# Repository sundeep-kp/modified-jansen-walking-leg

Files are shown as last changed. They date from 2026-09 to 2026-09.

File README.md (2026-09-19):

Full document here-- https://docs.google.com/document/d/1wQWvOZNvA1PLT6YzGUdqtGpzAtf10ug7fWzOEEy77QI/

preview (does not include assets for now, refer above document as recommended):

# Modified Jansen Walking Mechanism Report

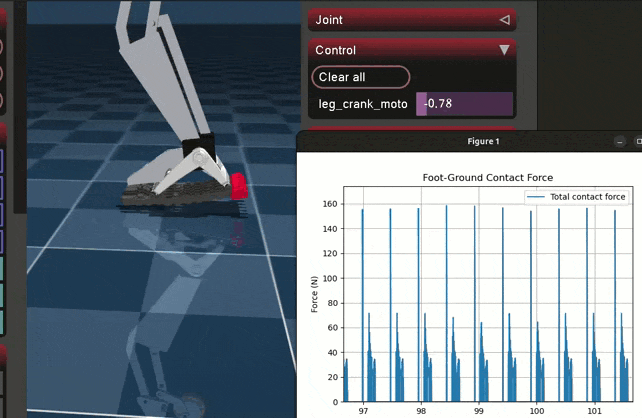
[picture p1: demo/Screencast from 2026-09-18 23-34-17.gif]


## Abstract
Theo Jansen's linkage is a well-known single-degree-of-freedom, eight-bar planar mechanism that converts rotary input into a leg-like walking trajectory. The objective of this project was to reduce the visual and part-count complexity of the standard Jansen leg — consolidating links where they do not affect the underlying kinematics — while keeping the mechanism at one degree of freedom and retaining a Jansen-like foot trajectory that closely matched human gait.

The design was carried out in SolidWorks, using its Motion Study add-in to verify the trajectory and animate the assembled mechanism, and later reconstructed in MuJoCo to evaluate contact dynamics and inform a physical build.

This reduced mechanism is a compact re-interpretation of the standard Jansen leg, in which several links were merged or removed for compactness without altering the underlying kinematic behaviour.

## 1. Introduction

Theo Jansen's linkage is a well-known single-degree-of-freedom, eight-bar planar mechanism that converts rotary input into a leg-like walking trajectory. The objective of this project was to reduce the visual and part-count complexity of the standard Jansen leg — consolidating links where they do not affect the underlying kinematics — while keeping the mechanism at one degree of freedom and retaining a Jansen-like foot trajectory that closely matched human gait. The design was carried out in SolidWorks, using its Motion Study add-in to verify the trajectory and animate the assembled mechanism, and later reconstructed in MuJoCo to evaluate contact dynamics and inform a physical build.

## 2. Mechanism Overview

The design is a reduced re-interpretation of the standard Jansen leg (Fig. 1), in which several links were merged or removed for compactness without altering the underlying kinematic behaviour.

Figure 1. The reduced mechanism (left) alongside the reference eight-bar Jansen linkage it is derived from (right).

### 2.1 Topology Reduction

The bottom horizontal link was removed and the two lower-left links were straightened into a single rigid link.

The upper-right horizontal link and the middle-right link were removed and replaced with one rigid bent link (shown in yellow in Fig. 3), which is a compaction choice rather than a kinematic change.

Ignoring the foot and the outermost link that drives it, the crank disk becomes the effective ground-mounted driver.

Figure 2. Before (left) and after (right) consolidating the lower-leg links into a single rigid member.

This reduction is visual rather than kinematic: the point where the lower right link meets the ternary (triangular) link is still pinned to the ground in the underlying sketch, even though this is not obvious from the solid geometry alone. The mechanism therefore reduces, functionally, to the same four-bar linkage present in the upper-right portion of the standard Jansen leg.

### 2.2 The Driving Four-Bar Subsystem

Colour-coding the assembly makes the reduction explicit (Fig. 3): the crank disk (black) rotates about the fixed ground pivot, driving the coupler link (blue), which in turn drives the ternary link (red). The ternary link is itself pinned to ground at a second, fixed point — completing the crank-rocker four-bar. The bent link (yellow) is an output link riding on the ternary link, carrying motion down to the lower leg (grey).

Figure 3. Colour-coded four-bar subsystem — crank (black), coupler (blue), ternary/rocker link (red), and the output bent link (yellow).

## 3. Methodology

The mechanism was built up incrementally in SolidWorks, verifying at each stage that the added constraints produced the intended single-degree-of-freedom behaviour before proceeding.

### 3.1 Ground Link and Ternary Link Placement

A disk was used as the ground link. One corner of the ternary link was pinned to this ground link at a separation of 15.8 mm (Fig. 4). The ternary link was chosen as the member fixed to ground because it plays the same structural role as the corresponding rocker link in the upper four-bar of the standard Jansen leg (Section 2.2); the 15.8 mm separation itself was arrived at empirically, by sweeping the dimension and observing its effect on the foot trajectory — this trade-off is examined in Section 4.2.

Figure 4. Ternary link sketch showing the fixed-pivot separation and hole geometry.

### 3.2 Crank–Coupler Assembly

A second disk was added as the crank, driven by a protruding input shaft, and connected to the ternary link through a coupler link (Fig. 5). This sub-assembly is a crank-rocker four-bar mechanism [1], with the crank providing continuous rotary input and the ternary link rocking in response.

Figure 5. Crank–coupler–ternary link four-bar sub-assembly.

### 3.3 Constraining the Lower Leg

With only the four-bar and the lower leg links connected, the assembly was under-constrained: each crank angle admitted multiple valid positions for the lower leg. An additional bent link, dimensioned as shown in Fig. 6 (9.86 mm and 12.83 mm segments at 139.31°), was introduced to remove this ambiguity and fully constrain the leg to a single configuration per input angle. The remaining sketch dimensions for this stage of the assembly are given in Fig. 7.

Figure 6. Bent-link geometry added to remove the residual assembly ambiguity.

Figure 7. Fully dimensioned four-bar and lower-leg sketch after the additional constraint was applied.

### 3.4 Leg Assembly, Mirroring, and Coupling

The completed leg was assembled and mirrored using SolidWorks' “create opposite hand components” option, and the mirrored files were saved and reassembled independently. Both legs were then joined by a connecting link (highlighted in blue in Fig. 8), which mechanically couples them to a single common input — keeping the overall mechanism at one degree of freedom while the two legs remain permanently offset by a phase difference. This offset was set experimentally (matching the legs at their extremum positions) to give a more natural walking gait.

Figure 8. Both legs coupled through a common connecting link (blue), sharing a single driven input.

### 3.5 Padding and Animation

Foot padding was added to each leg, and the assembly was driven with a simple rotary motor input in a SolidWorks Motion Study to animate the complete walking cycle (see Fig. 10, Section 5).

## 4. Kinematic Analysis

The modified mechanism retains several dimensional characteristics of the conventional Jansen linkage. Table 1 compares the measured link dimensions of this design against the closest corresponding dimensions of the standard Jansen linkage.

Table 1. Measured link dimensions versus standard Jansen proportions.

| Mechanism feature | Measured value (mm) | Closest Jansen value (mm) | Difference |
| --- | ---: | ---: | ---: |
| Upper crank / ternary-link connection | 23.24 | 15.0 | +54.9% |
| Upper fixed-pivot separation | 24.19 | 15.0 | +61.3% |
| Upper (major) coupler link | 44.02 | 41.5 | +6.1% |
| Major lower-leg link | 37.92 | 38.0 | −0.2% |
| Short lower connector | 14.58 | 15.0 | −2.8% |
| Small connector | 7.39 | 7.8 | −5.3% |
| Bent-link segment (short arm) | 9.86 | 7.8 | +26.4% |
| Bent-link segment (long arm) | 12.83 | 15.0 | −14.5% |
| Long lower-leg dimension | 61.08 | 61.9 | −1.3% |
| Upper positional dimension | 13.00 | 15.0 | −13.3% |
| Component offset | 43.17 | 41.5 | +4.0% |

The lower-leg dimensions (37.92 mm, 14.58 mm, 61.08 mm) track the standard Jansen values (38 mm, 15 mm, 61.9 mm) closely, to within about 3%. The upper four-bar dimensions, by contrast, deviate substantially — in places by more than 50% — reflecting the deliberate re-proportioning of this stage to accommodate the reduced topology and a more compact envelope.

### 4.1 Foot Trajectory

The traced path of a point at the centre of the foot's bottom face (Fig. 9) depends on both the input crank angle and the link dimensions and separations described above. To evaluate how human-like the resulting gait is, the traced path is compared directly against a reference human walking trajectory [7] and against the standard Jansen trajectory [6].

Figure 9a. Traced trajectory of the foot contact point of this mechanism, over one input revolution. (mirrored during simulation)

Figure 9b. Reference human walker gait trajectory [7].

Figure 9c. Reference standard Jansen mechanism gait trajectory [6].

### 4.2 Effect of the 15.8 mm Pivot Separation

The separation between the ground pivot and the ternary link (Section 3.1) was found to directly shape the trajectory:

- At 15.8 mm, the trajectory is somewhat front-heavy.
- Increasing the separation moves the path closer to the stretched-D shape of the standard Jansen trajectory.
- Increasing it further makes the trajectory back-heavy.
- Decreasing it too far causes the four-bar to lose continuous rotary motion — consistent with the mechanism moving out of a Grashof-satisfying link proportion, though this was not formally verified against Grashof's condition in this iteration.

The final value of 15.8 mm was retained because it produces a trajectory whose apex sits slightly forward of centre, relative to the standard Jansen path. This was a deliberate design choice, motivated by three considerations: it mimics human stride, where the apex of foot motion typically sits ahead of the body rather than at its midpoint; it reduces the stride length, improving stability and reliability; and it produces a smoother displacement curve, with a more gradual transition from the rising to the falling phase of the stride.

### 4.3 Results

The completed assembly was driven with a simple rotary motor input and animated in SolidWorks Motion Study (Fig. 10), confirming that the coupled two-leg mechanism produces continuous, single-DOF walking motion with the intended phase offset between legs.

Figure 10. Animated mechanism during a Motion Study walking-cycle simulation.

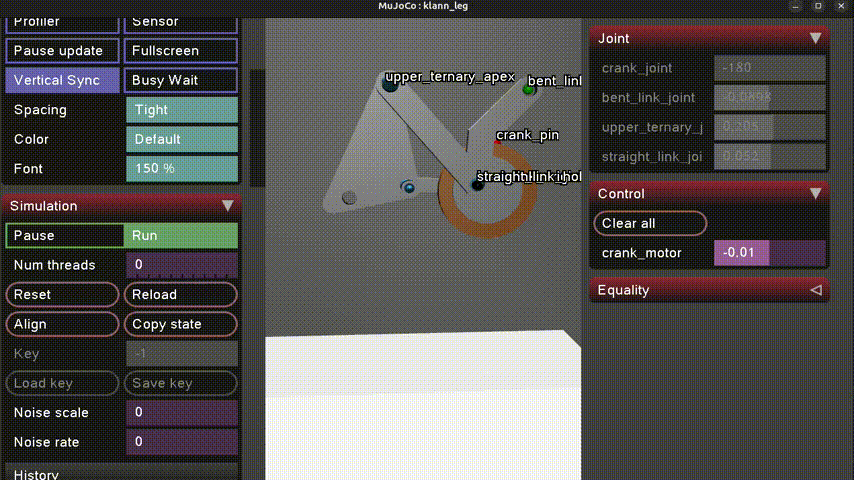
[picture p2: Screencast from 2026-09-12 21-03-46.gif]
Animated mechanism during Motion Study


Simulation video: https://youtu.be/PFEDmKlTlRk?si=vWkerZGaBaEz1gjp

## 5. Simulation

To evaluate contact dynamics that are not readily accessible in the SolidWorks Motion Study — in particular, foot–ground contact forces through a compliant shoe — the mechanism was reconstructed as a physics simulation in MuJoCo.

### 5.1 Link Naming and Digitised Geometry

Before reconstructing the mechanism outside SolidWorks, every link and joint was given a consistent name, and every relevant dimension was measured directly from the CAD model. This naming convention (Fig. 11) was used throughout the MuJoCo model and its XML description.

Figure 11. Link and joint naming convention used for the MuJoCo reconstruction.

The corresponding measured dimensions are summarised in Table 2, with the upper ternary link's sketch dimensions shown as a representative example in Fig. 12. The foot outline was digitised as a series of edge lengths in the same way — Fig. 13 shows one representative measurement — in order to reproduce the exact collision geometry of the physical foot in simulation.

Table 2. Named-link dimensions used for the MuJoCo reconstruction.

| Named link | Feature | Value |
| --- | --- | --- |
| Upper ternary link | joint_3–joint_4 | 21.00 mm |
| Upper ternary link | joint_4–joint_5 | 12.00 mm |
| Upper ternary link | joint_3–joint_5 | 24.19 mm |
| Upper ternary link | Enclosed area / perimeter | 146.87 mm² / 53.41 mm |
| Straight link (upper ternary → lower ternary) | Length | 15.80 mm |
| Bent link (upper ternary → lower ternary) | Segments / angle | see Fig. 6–7 |
| Lower ternary link | Long edge | 37.72 mm |
| Lower ternary link | Offset / short edge | 2.50 mm |
| Lower ternary link | Included angle | 153.74° |
| Lower ternary link | Third edge | 11.33 mm |
| Foot link | Main structural dims | 13.00 mm, 61.08 mm (R1.00 fillet) |
| Foot link | Digitised outline segments | 14.69, 22.66, 25.48, 2.3, 20.7, 15.33, 7.28, 3.12 mm |

Figure 12. Upper ternary link sketch dimensions (joint_3–joint_4–joint_5), representative of the dimensioning pass summarised in Table 2.

Figure 13. Representative foot-outline edge measurement; the full outline was digitised edge-by-edge in the same way for the simulation collision mesh.

### 5.2 MJCF Reconstruction and Closing Kinematic Loops

The mechanism was recreated by importing meshes extracted from the SolidWorks assembly, one link at a time, into the MuJoCo viewer using the native MJCF format. A closed-loop four-bar linkage example [8] was used as a reference for handling kinematic loops in MuJoCo, since MJCF natively describes open kinematic trees.

A joint was defined for each parent–child link pair. To close the two kinematic loops (the driving four-bar, and the lower-leg loop), equality constraints were used to connect pairs of defined sites — specifically, coincident points on the “straight link” and “base link” bodies that should stay joined during motion.

Figure 14. Initial four-bar sub-mechanism reconstructed in the MuJoCo viewer.

Initially, the constrained bodies did not feel rigidly connected — instead behaving as though attracted like magnets rather than pinned together. Investigating further, this was traced to MuJoCo's equality constraints being soft constraints by default: the solver finds constraint forces parameterised by impedance, stiffness (k), and damping (b), and the solref parameter controls the reference acceleration — i.e. how quickly the constraint tries to correct a violation. Tuning these parameters resolved the apparent “magnetic” behaviour and produced a properly closed kinematic loop.

Figure 15. Equality-constrained sites (labelled) closing the four-bar kinematic loop.

Figure 16. Full single-leg mechanism (“klann_leg”) reconstructed and closed in MuJoCo.

Figure 17. Iterating on the MJCF description (modified_jansen_leg.xml) alongside the live MuJoCo viewer.

### 5.3 Deformable Shoe and Contact Physics

To estimate realistic foot–ground contact behaviour, a deformable shoe body was added at the foot link, modelled as a soft body rather than a rigid one.

Attempt 1: with a low number of mesh nodes, the deformable body was unstable and produced unreliable contact behaviour.

Increasing the node count produced stable results; the overall system was then scaled to match adult foot dimensions.

With most of the system stable, the deformable shoe began passing through the floor plane under load.

Figure 18. Early instability: the deformable shoe penetrating through the floor plane.

This penetration was resolved by tuning the shoe's approximate material properties and the solver's contact-correction behaviour, referring to MuJoCo's contact-physics documentation [9] for the relevant parameters:

```text
young = "8e4"          (Young's modulus, lowered for visualisation purposes)
damping = "0.001"
poisson = "0.2"
solref = "0.003 1"    (controls how quickly the constraint corrects penetration)
solimp = ".95 .99 .0001"
```

The width of the floor plane was also increased to prevent contact “bleeding” under a high node count, following a known issue reported against MuJoCo on GitHub.

Figure 19. Deformable shoe resting stably on the floor plane after parameter tuning.

Figure 20. Shoe visually attached to the foot link of the reconstructed mechanism.

### 5.4 Simulated Contact Loading

With the geometry and contact model in place, the link dimensions and masses were finalised, assuming the links to be aluminium, the shoe to be the mass of a standard adult male shoe (~300 g), and the drive motor's weight to initially be that of a standard 1.7 N motor. Figure 21 shows the theoretical contact force at the FSR location under the base of the big toe, over one walking cycle, at an input torque of 0.08 N·m.

Figure 21. Theoretical contact force at the big-toe FSR location over one walking cycle, at 0.08 N·m input torque.

## 6. Proposed Hardware

Based on the simulated loading in Section 6.4, the following hardware was proposed for a physical build of the mechanism.

### 6.1 Proposed Components

- 12 V OG555 geared motor with encoder — crank drive.
- ESP32 — main microcontroller.
- BTS7960 (or equivalent high-power H-bridge capable of handling the 12 V motor).
- AS5600 — for measuring foot orientation at a given time.
- MPU6050 — standard IMU used for acceleration measurement in this class of project.
- Adafruit Alpha MF01A-N-221-A05 force sensor (rated 1–100 N contact force, <1 ms response, with a mature ESP32-compatible library), used at three standard foot contact points: heel, big toe, and little toe. Alternative: load cell + HX711.
- Mean Well LRS-75-12 power supply — 12 V, 6 A adjustable, providing headroom for future add-ons.

### 6.2 Control Architecture

The proposed control loop drives the crank through a speed/position controller on the ESP32, and closes the loop on foot contact and orientation sensing:

```text
+---------------------------+
|          ESP32 MCU         |
|                             |
Desired crank ---->|  Speed / Position Controller|
speed          |             |               |
+-------------+---------------+
| PWM / DIR
v
+--------------+
| BTS7960 /    |
| H-Bridge     |
+------+-------+
|
+------v-------+
| 12 V OG555   |
| Geared Motor |
+------+-------+
|
CRANK
|
+------v-------+
|   LINKAGE    |
+------+-------+
|
FOOT
|
+-------------------+-------------------+
|                   |                   |
Heel FSR           Big-toe FSR        Little-toe FSR
|                   |                   |
+-------------------+-------------------+
|
v
+--------------+
|    ESP32     |
|  Contact     |
|  detection   |
+--------------+
Motor encoder ------------------------------> ESP32
AS5600 --------------------------------------> ESP32
MPU6050 -------------------------------------> ESP32
```

Figure 22. Proposed control architecture: crank speed/position control, closed with foot-contact and orientation sensing.

## 7. Conclusion and Future Work

This project reduced the standard eight-bar Jansen leg to a more compact topology built around a single crank-rocker four-bar, while keeping the mechanism at one degree of freedom and tuning its foot trajectory to sit closer to a human gait than the standard Jansen path. The lower-leg dimensions retained close agreement with the classical Jansen proportions (Section 4), while the upper four-bar was deliberately re-proportioned for the reduced topology and a more compact envelope. Mirroring and coupling the leg into a two-leg, single-input assembly, and animating it in SolidWorks Motion Study, confirmed that the design behaves as intended (Section 5).

The mechanism was then carried substantially further than a CAD exercise: it was reconstructed link-by-link as a physics simulation in MuJoCo, with closed kinematic loops, a deformable contact shoe, and a theoretical contact-force estimate at the big toe (Section 6). That simulated loading, in turn, informed a concrete proposed hardware architecture — drive motor, motor driver, microcontroller, orientation and contact sensing, and power supply — with a defined control loop from desired crank speed through to foot-contact detection (Section 7). Taken together, the project now spans the full path from a first-principles kinematic reduction to a build-ready hardware and control specification.

The most valuable next steps follow directly from where this iteration stopped short:

- Formally verifying the degrees of freedom of the coupled two-leg assembly and the Grashof condition of the driving four-bar using Grübler's equation, rather than relying on the empirical observation in Section 4.2.
- Quantifying the trajectory sweep described in Section 4.2 with a table or plot of pivot separation versus trajectory apex position, instead of the qualitative front-heavy/back-heavy description used here.
- Validating the MuJoCo contact-force estimate (Section 6.4) against the physical prototype once built, and tuning the deformable shoe parameters accordingly.
- Physically fabricating the mechanism and the proposed hardware in Section 7, and closing the control loop on real sensor data rather than simulated values.

## References

- [1] Four bar crank-rocker mechanism demonstration. https://www.youtube.com/watch?v=hrvIBtrDNV0
- [2] Theo Jansen mechanism walking demonstration. https://www.youtube.com/watch?v=clGEbGLUyoQ
- [3] Theo Jansen mechanism build/analysis video. https://www.youtube.com/watch?v=vAEZ4BYAmGE&t=120s
- [4] The Jansen leg: a 1-degree-of-freedom planar linkage of eight links, seven revolute joints. ResearchGate figure. https://www.researchgate.net/figure/The-Jansen-leg-a-1-degree-of-freedom-planar-linkage-of-eight-links-seven-revolute_fig2_277606519
- [5] Educational model of the Theo Jansen mechanism. https://www.printables.com/model/1503557-educational-model-of-theo-jansen-mechanism
- [6] Theo Jansen mechanism reference video. https://www.youtube.com/watch?v=FFuDU1Uiu9k
- [7] Reference human walker gait — acceleration carries the local inversion effect in biological motion perception. https://www.researchgate.net/figure/The-full-gait-trajectory-with-the-10-starting-positions-A-and-the-individual-150-ms_fig1_24187266
- [8] Closed-loop simulation example (four-bar linkage) in MuJoCo, using equality constraints. https://github.com/google-deepmind/mujoco/issues/172
- [9] Reference for deformable-body contact physics parameters used in Section 6.3. https://arxiv.org/html/2411.14701v1

### Project Files

- [modified_jansen_leg.xml](modified_jansen_leg.xml)
- [modified_jansen_leg_adult_male_shoe.xml](modified_jansen_leg_adult_male_shoe.xml)
- [modified_jansen_leg_scaled_4x.xml](modified_jansen_leg_scaled_4x.xml)
- [modified_jansen_leg_visual_shoe.xml](modified_jansen_leg_visual_shoe.xml)
- [reference.xml](reference.xml)
- [template_mujoco.py](template_mujoco.py)

## Appendix: Repository Snapshot

This folder contains the MuJoCo model files, the SolidWorks-derived mesh assets, and the report media used for the walking mechanism design and validation work.

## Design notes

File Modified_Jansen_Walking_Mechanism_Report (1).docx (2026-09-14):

Analysis and Implementation of a Modified Jansen-Based Walking Mechanism

Design log and kinematic analysis of a reduced-topology, single-DOF leg mechanism

Simulation demo: https://youtu.be/PFEDmKlTlRk?si=vWkerZGaBaEz1gjp

# Abstract

This report documents the design and kinematic analysis of a reduced Jansen-type walking mechanism. The mechanism's core motion-generation subsystem is a crank-rocker four-bar linkage, to which additional links are coupled to shape the foot trajectory. Starting from the standard eight-bar Jansen leg, several links were consolidated or re-routed to simplify the topology while preserving single-degree-of-freedom motion and mimicking a more human-like gait trajectory. The resulting mechanism was implemented in SolidWorks, mirrored to produce a second leg, and coupled to a common input so that both legs move from a single driven crank. Measured link dimensions are compared against the standard Jansen proportions, the effect of one key dimension on the shape of the foot trajectory is analysed, and the mechanism is reconstructed as a physics simulation in MuJoCo — including a deformable shoe and contact-force estimation — alongside a proposed hardware architecture for physical realisation.

# Table of Contents

1. Introduction ................................................................................................................................................ 1

2. Mechanism Overview .............................................................................................................................. 1

2.1 Topology Reduction ....................................................................................................................... 1

2.2 The Driving Four-Bar Subsystem ................................................................................................. 1

3. Methodology ............................................................................................................................................ 1

3.1 Ground Link and Ternary Link Placement ................................................................................ 1

3.2 Crank–Coupler Assembly ................................................................................................................ 1

3.3 Constraining the Lower Leg ........................................................................................................... 1

3.4 Leg Assembly, Mirroring, and Coupling ................................................................................... 1

3.5 Padding and Animation .................................................................................................................. 1

4. Kinematic Analysis ................................................................................................................................... 1

4.1 Foot Trajectory ................................................................................................................................. 2

4.2 Effect of the 15.8 mm Pivot Separation ........................................................................................ 2

4.3 Results ................................................................................................................................................ 2

5. Simulation ................................................................................................................................................. 2

5.1 Link Naming and Digitised Geometry ........................................................................................ 2

5.2 MJCF Reconstruction and Closing Kinematic Loops ............................................................. 3

5.3 Deformable Shoe and Contact Physics ....................................................................................... 3

5.4 Simulated Contact Loading ........................................................................................................... 4

6. Proposed Hardware ................................................................................................................................ 4

6.1 Proposed Components .................................................................................................................... 4

6.2 Control Architecture ...................................................................................................................... 4

7. Conclusion and Future Work ................................................................................................................ 5

References ..................................................................................................................................................... 5

# 1. Introduction

Theo Jansen's linkage is a well-known single-degree-of-freedom, eight-bar planar mechanism that converts rotary input into a leg-like walking trajectory. The objective of this project was to reduce the visual and part-count complexity of the standard Jansen leg — consolidating links where they do not affect the underlying kinematics — while keeping the mechanism at one degree of freedom and retaining a Jansen-like foot trajectory that closely matched human gait. The design was carried out in SolidWorks, using its Motion Study add-in to verify the trajectory and animate the assembled mechanism, and later reconstructed in MuJoCo to evaluate contact dynamics and inform a physical build.

# 2. Mechanism Overview

The design is a reduced re-interpretation of the standard Jansen leg (Fig. 1), in which several links were merged or removed for compactness without altering the underlying kinematic behaviour.

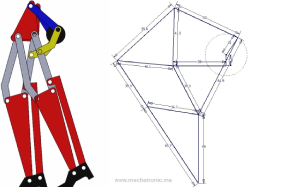
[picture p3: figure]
Comparison of reduced mechanism to standard Jansen linkage

Figure 1. The reduced mechanism (left) alongside the reference eight-bar Jansen linkage it is derived from (right).

## 2.1 Topology Reduction

- The bottom horizontal link was removed and the two lower-left links were straightened into a single rigid link.
- The upper-right horizontal link and the middle-right link were removed and replaced with one rigid bent link (shown in yellow in Fig. 3), which is a compaction choice rather than a kinematic change.
- Ignoring the foot and the outermost link that drives it, the crank disk becomes the effective ground-mounted driver.

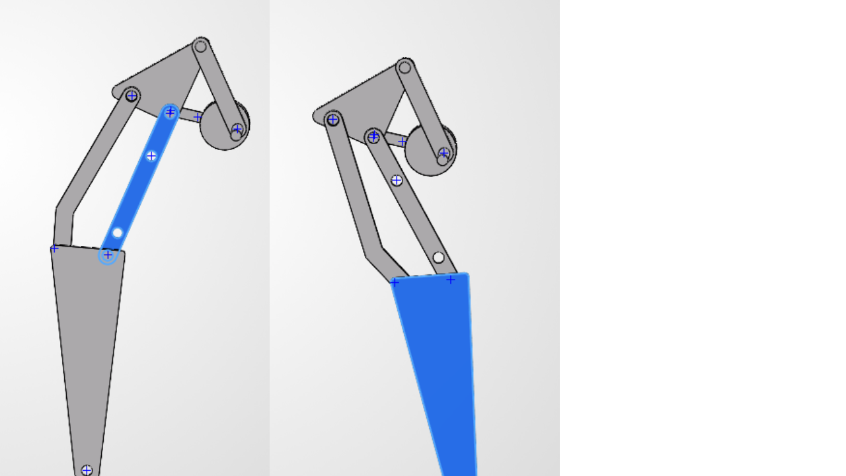
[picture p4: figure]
Before and after link consolidation

Figure 2. Before (left) and after (right) consolidating the lower-leg links into a single rigid member.

This reduction is visual rather than kinematic: the point where the lower right link meets the ternary (triangular) link is still pinned to the ground in the underlying sketch, even though this is not obvious from the solid geometry alone. The mechanism therefore reduces, functionally, to the same four-bar linkage present in the upper-right portion of the standard Jansen leg.

## 2.2 The Driving Four-Bar Subsystem

Colour-coding the assembly makes the reduction explicit (Fig. 3): the crank disk (black) rotates about the fixed ground pivot, driving the coupler link (blue), which in turn drives the ternary link (red). The ternary link is itself pinned to ground at a second, fixed point — completing the crank-rocker four-bar. The bent link (yellow) is an output link riding on the ternary link, carrying motion down to the lower leg (grey).

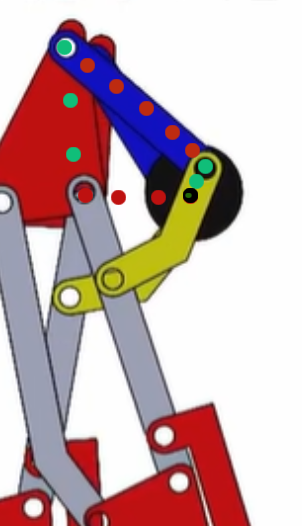
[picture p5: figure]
Color coded four bar subsystem

Figure 3. Colour-coded four-bar subsystem — crank (black), coupler (blue), ternary/rocker link (red), and the output bent link (yellow).

# 3. Methodology

The mechanism was built up incrementally in SolidWorks, verifying at each stage that the added constraints produced the intended single-degree-of-freedom behaviour before proceeding.

## 3.1 Ground Link and Ternary Link Placement

A disk was used as the ground link. One corner of the ternary link was pinned to this ground link at a separation of 15.8 mm (Fig. 4). The ternary link was chosen as the member fixed to ground because it plays the same structural role as the corresponding rocker link in the upper four-bar of the standard Jansen leg (Section 2.2); the 15.8 mm separation itself was arrived at empirically, by sweeping the dimension and observing its effect on the foot trajectory — this trade-off is examined in Section 4.2.

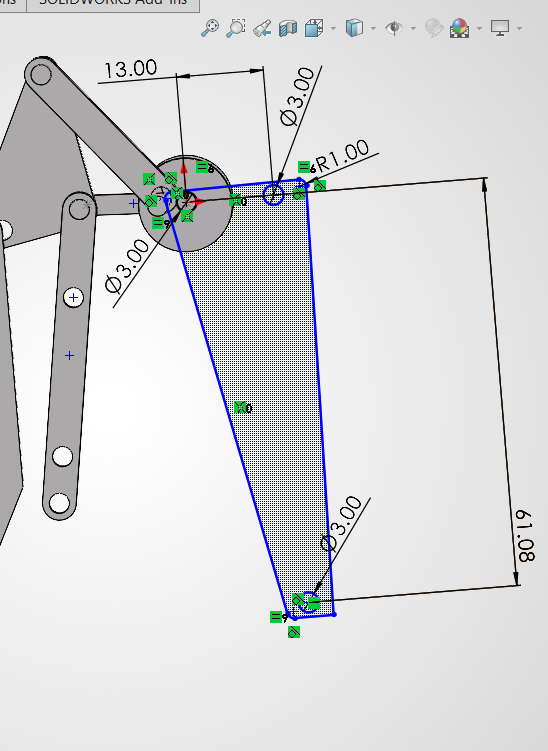
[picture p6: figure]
Ternary link dimension sketch

Figure 4. Ternary link sketch showing the fixed-pivot separation and hole geometry.

## 3.2 Crank–Coupler Assembly

A second disk was added as the crank, driven by a protruding input shaft, and connected to the ternary link through a coupler link (Fig. 5). This sub-assembly is a crank-rocker four-bar mechanism [1], with the crank providing continuous rotary input and the ternary link rocking in response.

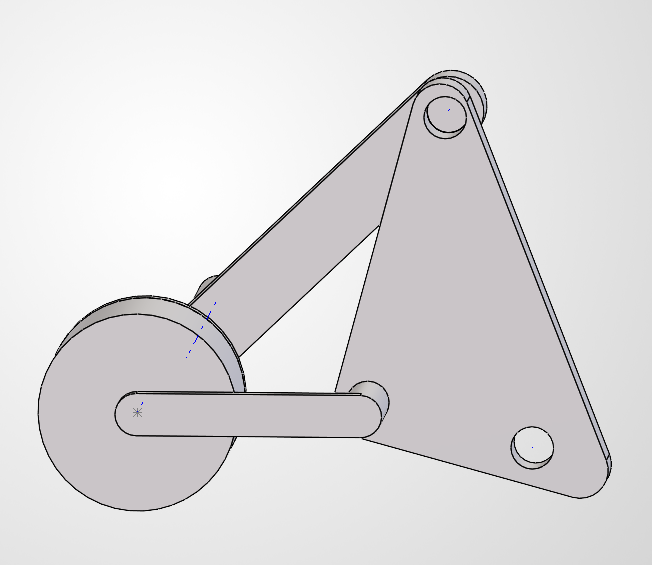
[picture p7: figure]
Crank coupler ternary four bar assembly

Figure 5. Crank–coupler–ternary link four-bar sub-assembly.

## 3.3 Constraining the Lower Leg

With only the four-bar and the lower leg links connected, the assembly was under-constrained: each crank angle admitted multiple valid positions for the lower leg. An additional bent link, dimensioned as shown in Fig. 6 (9.86 mm and 12.83 mm segments at 139.31°), was introduced to remove this ambiguity and fully constrain the leg to a single configuration per input angle. The remaining sketch dimensions for this stage of the assembly are given in Fig. 7.

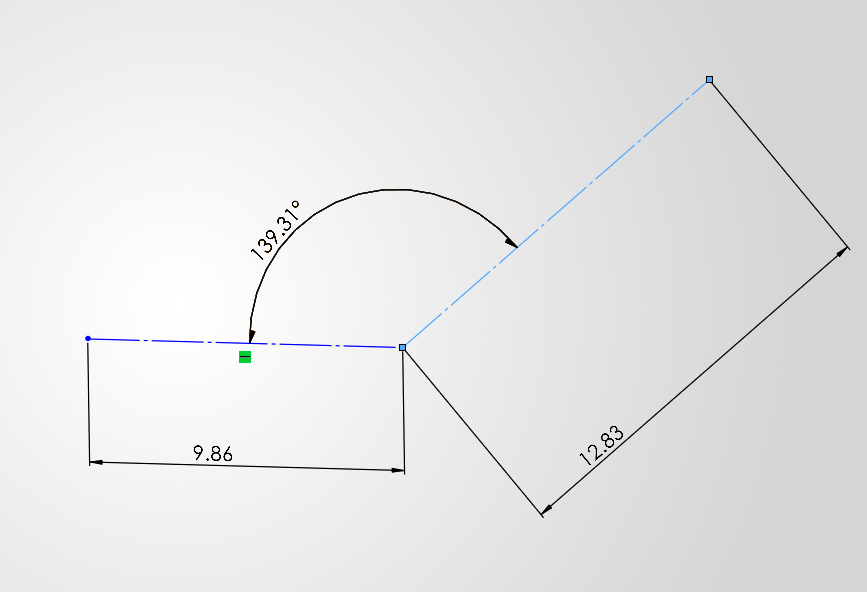
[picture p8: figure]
Bent link dimension sketch

Figure 6. Bent-link geometry added to remove the residual assembly ambiguity.

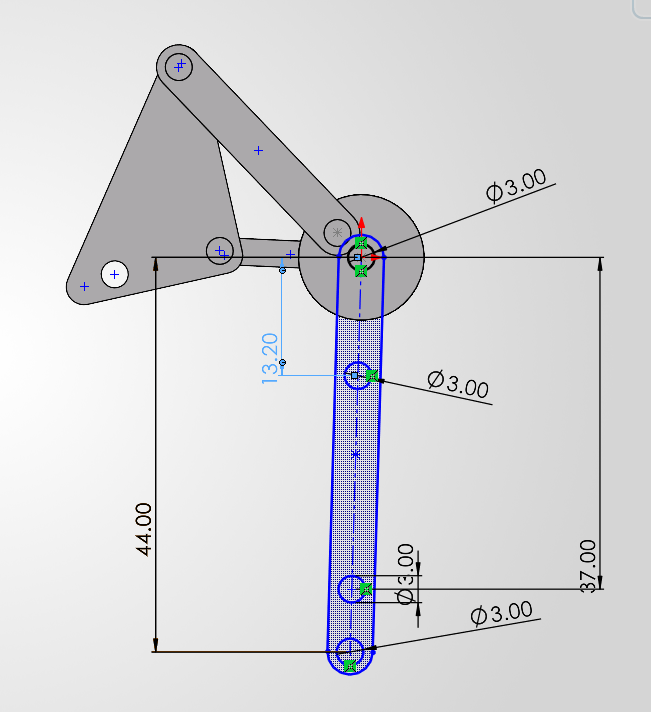
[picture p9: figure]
Fully dimensioned four bar and lower leg sketch

Figure 7. Fully dimensioned four-bar and lower-leg sketch after the additional constraint was applied.

## 3.4 Leg Assembly, Mirroring, and Coupling

The completed leg was assembled and mirrored using SolidWorks' “create opposite hand components” option, and the mirrored files were saved and reassembled independently. Both legs were then joined by a connecting link (highlighted in blue in Fig. 8), which mechanically couples them to a single common input — keeping the overall mechanism at one degree of freedom while the two legs remain permanently offset by a phase difference. This offset was set experimentally (matching the legs at their extremum positions) to give a more natural walking gait.

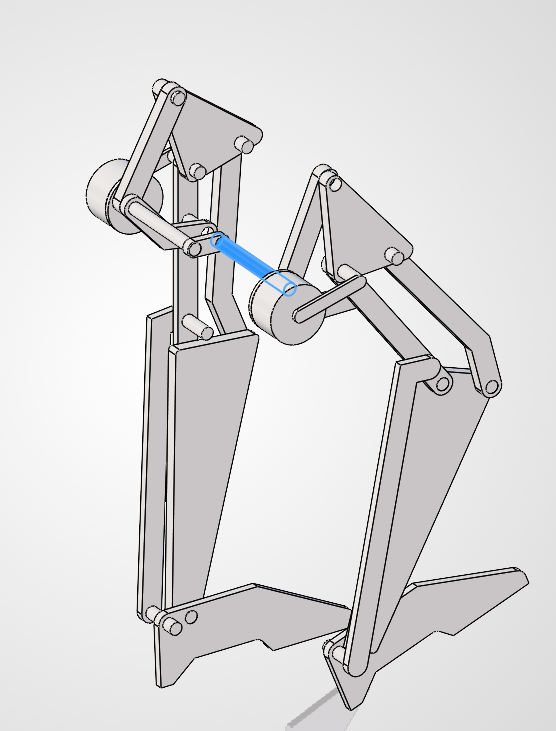
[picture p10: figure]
Coupled two leg assembly

Figure 8. Both legs coupled through a common connecting link (blue), sharing a single driven input.

## 3.5 Padding and Animation

Foot padding was added to each leg, and the assembly was driven with a simple rotary motor input in a SolidWorks Motion Study to animate the complete walking cycle (see Fig. 10, Section 5).

# 4. Kinematic Analysis

The modified mechanism retains several dimensional characteristics of the conventional Jansen linkage. Table 1 compares the measured link dimensions of this design against the closest corresponding dimensions of the standard Jansen linkage.

Table 1. Measured link dimensions versus standard Jansen proportions.

Mechanism feature | Measured value (mm) | Closest Jansen value (mm) | Difference
Upper crank / ternary-link connection | 23.24 | 15.0 | +54.9%
Upper fixed-pivot separation | 24.19 | 15.0 | +61.3%
Upper (major) coupler link | 44.02 | 41.5 | +6.1%
Major lower-leg link | 37.92 | 38.0 | −0.2%
Short lower connector | 14.58 | 15.0 | −2.8%
Small connector | 7.39 | 7.8 | −5.3%
Bent-link segment (short arm) | 9.86 | 7.8 | +26.4%
Bent-link segment (long arm) | 12.83 | 15.0 | −14.5%
Long lower-leg dimension | 61.08 | 61.9 | −1.3%
Upper positional dimension | 13.00 | 15.0 | −13.3%
Component offset | 43.17 | 41.5 | +4.0%

The lower-leg dimensions (37.92 mm, 14.58 mm, 61.08 mm) track the standard Jansen values (38 mm, 15 mm, 61.9 mm) closely, to within about 3%. The upper four-bar dimensions, by contrast, deviate substantially — in places by more than 50% — reflecting the deliberate re-proportioning of this stage to accommodate the reduced topology and a more compact envelope.

## 4.1 Foot Trajectory

The traced path of a point at the centre of the foot's bottom face (Fig. 9) depends on both the input crank angle and the link dimensions and separations described above. To evaluate how human-like the resulting gait is, the traced path is compared directly against a reference human walking trajectory [7] and against the standard Jansen trajectory [6].

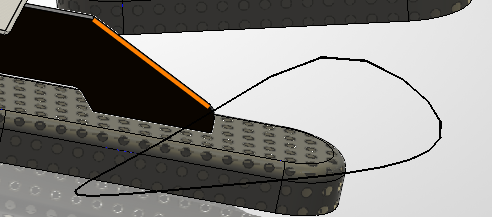
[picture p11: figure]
Foot trajectory trace of this mechanism

Figure 9a. Traced trajectory of the foot contact point of this mechanism, over one input revolution. (mirrored during simulation)

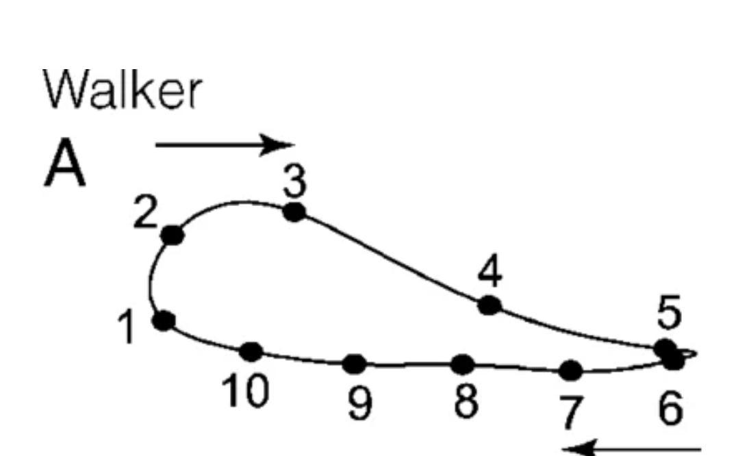
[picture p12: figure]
Reference human gait trajectory

Figure 9b. Reference human walker gait trajectory [7].

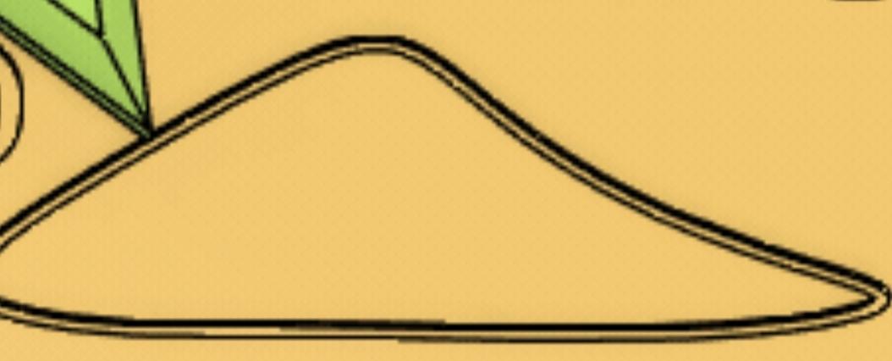
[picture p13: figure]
Reference standard Jansen gait trajectory

Figure 9c. Reference standard Jansen mechanism gait trajectory [6].

## 4.2 Effect of the 15.8 mm Pivot Separation

The separation between the ground pivot and the ternary link (Section 3.1) was found to directly shape the trajectory:

- At 15.8 mm, the trajectory is somewhat front-heavy.
- Increasing the separation moves the path closer to the stretched-D shape of the standard Jansen trajectory.
- Increasing it further makes the trajectory back-heavy.
- Decreasing it too far causes the four-bar to lose continuous rotary motion — consistent with the mechanism moving out of a Grashof-satisfying link proportion, though this was not formally verified against Grashof's condition in this iteration.

The final value of 15.8 mm was retained because it produces a trajectory whose apex sits slightly forward of centre, relative to the standard Jansen path. This was a deliberate design choice, motivated by three considerations: it mimics human stride, where the apex of foot motion typically sits ahead of the body rather than at its midpoint; it reduces the stride length, improving stability and reliability; and it produces a smoother displacement curve, with a more gradual transition from the rising to the falling phase of the stride.

# 4.3 Results

The completed assembly was driven with a simple rotary motor input and animated in SolidWorks Motion Study (Fig. 10), confirming that the coupled two-leg mechanism produces continuous, single-DOF walking motion with the intended phase offset between legs.

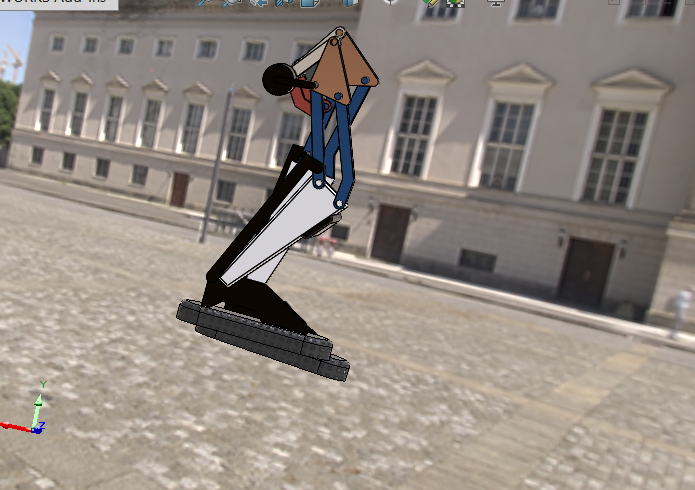
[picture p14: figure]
Animated walking mechanism

Figure 10. Animated mechanism during a Motion Study walking-cycle simulation.

Simulation video: https://youtu.be/PFEDmKlTlRk?si=vWkerZGaBaEz1gjp

# 5. Simulation

To evaluate contact dynamics that are not readily accessible in the SolidWorks Motion Study — in particular, foot–ground contact forces through a compliant shoe — the mechanism was reconstructed as a physics simulation in MuJoCo.

## 5.1 Link Naming and Digitised Geometry

Before reconstructing the mechanism outside SolidWorks, every link and joint was given a consistent name, and every relevant dimension was measured directly from the CAD model. This naming convention (Fig. 11) was used throughout the MuJoCo model and its XML description.

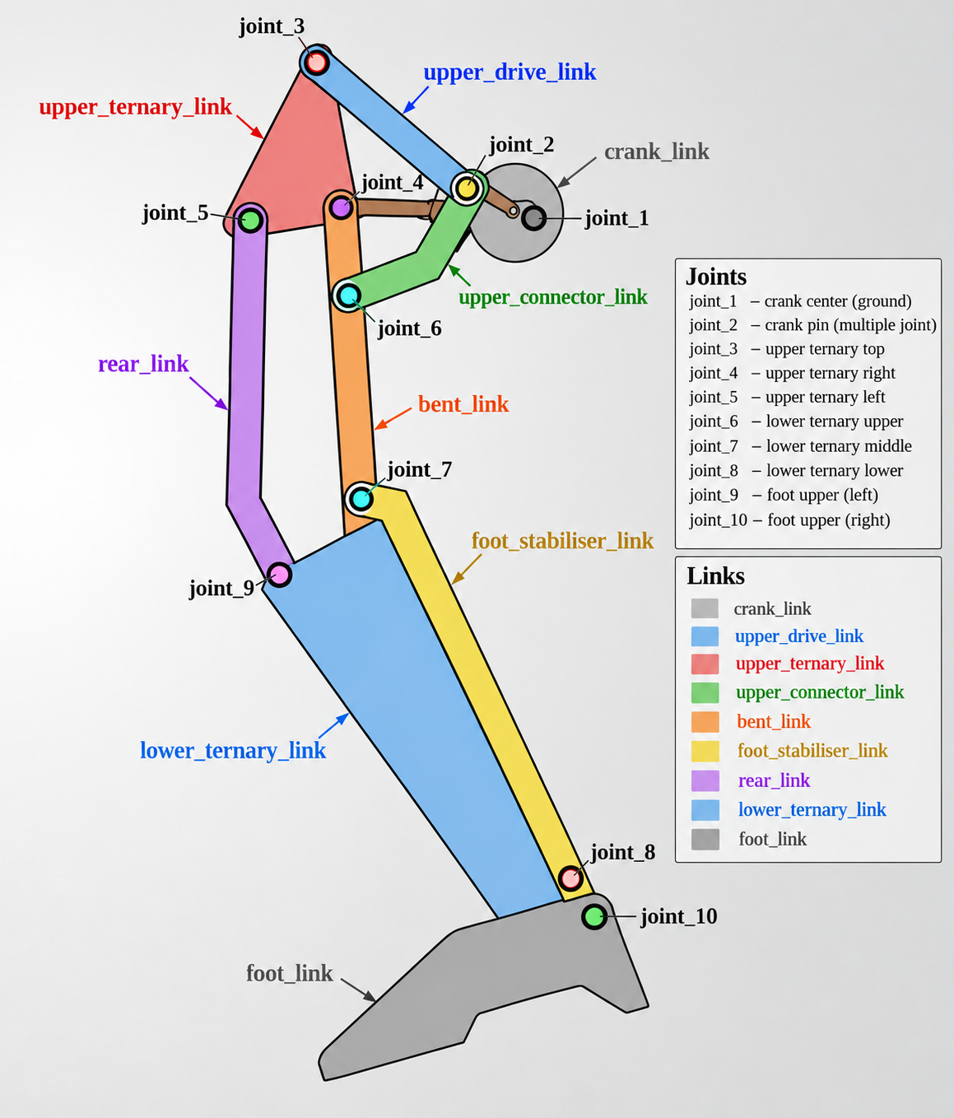
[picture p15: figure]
Link and joint naming diagram

Figure 11. Link and joint naming convention used for the MuJoCo reconstruction.

The corresponding measured dimensions are summarised in Table 2, with the upper ternary link's sketch dimensions shown as a representative example in Fig. 12. The foot outline was digitised as a series of edge lengths in the same way — Fig. 13 shows one representative measurement — in order to reproduce the exact collision geometry of the physical foot in simulation.

Table 2. Named-link dimensions used for the MuJoCo reconstruction.

Named link | Feature | Value
Upper ternary link | joint_3–joint_4 | 21.00 mm
Upper ternary link | joint_4–joint_5 | 12.00 mm
Upper ternary link | joint_3–joint_5 | 24.19 mm
Upper ternary link | Enclosed area / perimeter | 146.87 mm² / 53.41 mm
Straight link (upper ternary → lower ternary) | Length | 15.80 mm
Bent link (upper ternary → lower ternary) | Segments / angle | see Fig. 6–7
Lower ternary link | Long edge | 37.72 mm
Lower ternary link | Offset / short edge | 2.50 mm
Lower ternary link | Included angle | 153.74°
Lower ternary link | Third edge | 11.33 mm
Foot link | Main structural dims | 13.00 mm, 61.08 mm (R1.00 fillet)
Foot link | Digitised outline segments | 14.69, 22.66, 25.48, 2.3, 20.7, 15.33, 7.28, 3.12 mm

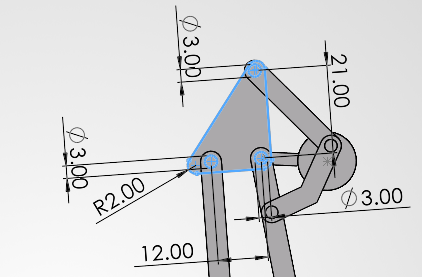
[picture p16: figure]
Upper ternary link dimensions

Figure 12. Upper ternary link sketch dimensions (joint_3–joint_4–joint_5), representative of the dimensioning pass summarised in Table 2.

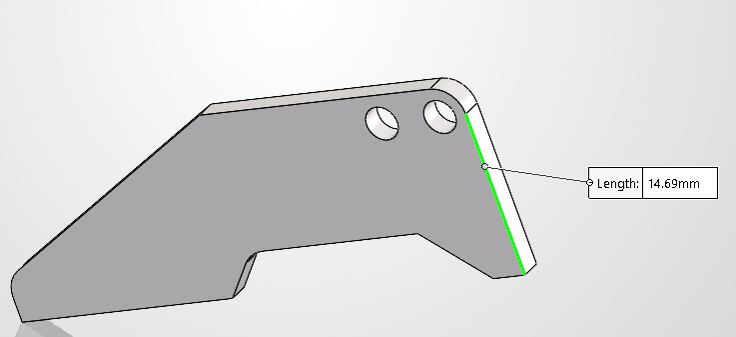
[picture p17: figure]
Foot outline edge measurement sample

Figure 13. Representative foot-outline edge measurement; the full outline was digitised edge-by-edge in the same way for the simulation collision mesh.

## 5.2 MJCF Reconstruction and Closing Kinematic Loops

The mechanism was recreated by importing meshes extracted from the SolidWorks assembly, one link at a time, into the MuJoCo viewer using the native MJCF format. A closed-loop four-bar linkage example [8] was used as a reference for handling kinematic loops in MuJoCo, since MJCF natively describes open kinematic trees.

A joint was defined for each parent–child link pair. To close the two kinematic loops (the driving four-bar, and the lower-leg loop), equality constraints were used to connect pairs of defined sites — specifically, coincident points on the “straight link” and “base link” bodies that should stay joined during motion.

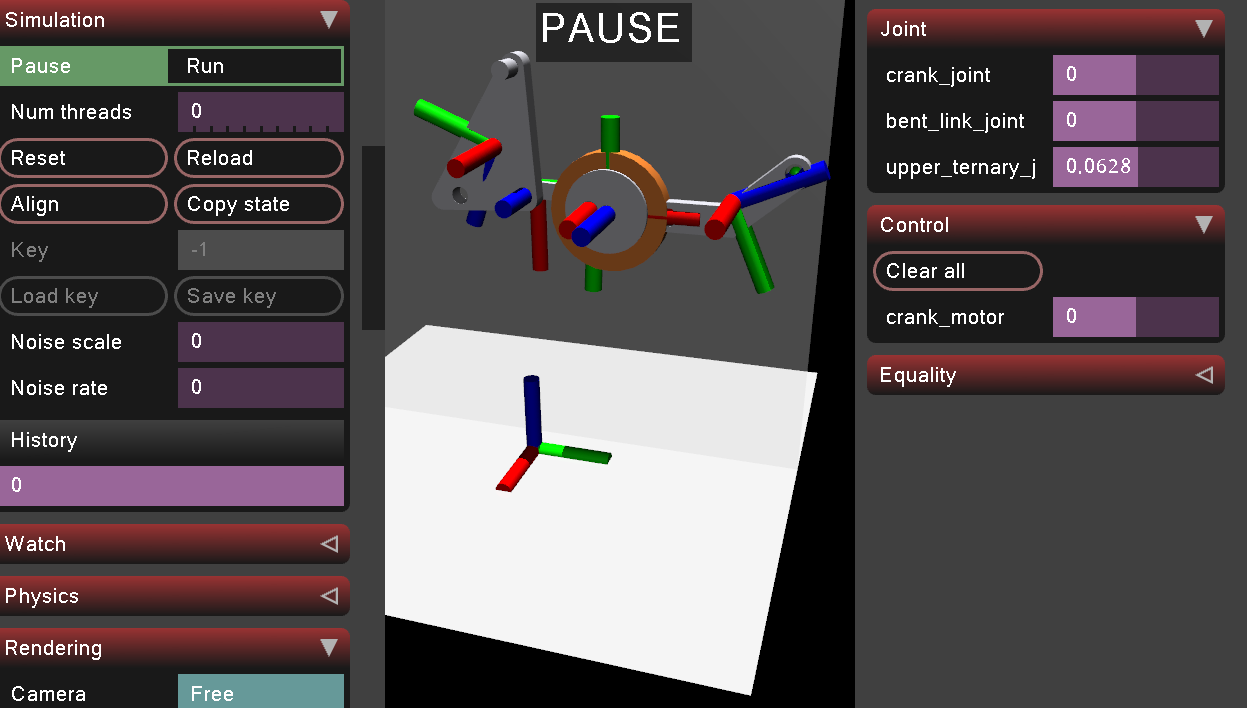
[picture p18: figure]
Initial four bar mechanism in MuJoCo

Figure 14. Initial four-bar sub-mechanism reconstructed in the MuJoCo viewer.

Initially, the constrained bodies did not feel rigidly connected — instead behaving as though attracted like magnets rather than pinned together. Investigating further, this was traced to MuJoCo's equality constraints being soft constraints by default: the solver finds constraint forces parameterised by impedance, stiffness (k), and damping (b), and the solref parameter controls the reference acceleration — i.e. how quickly the constraint tries to correct a violation. Tuning these parameters resolved the apparent “magnetic” behaviour and produced a properly closed kinematic loop.

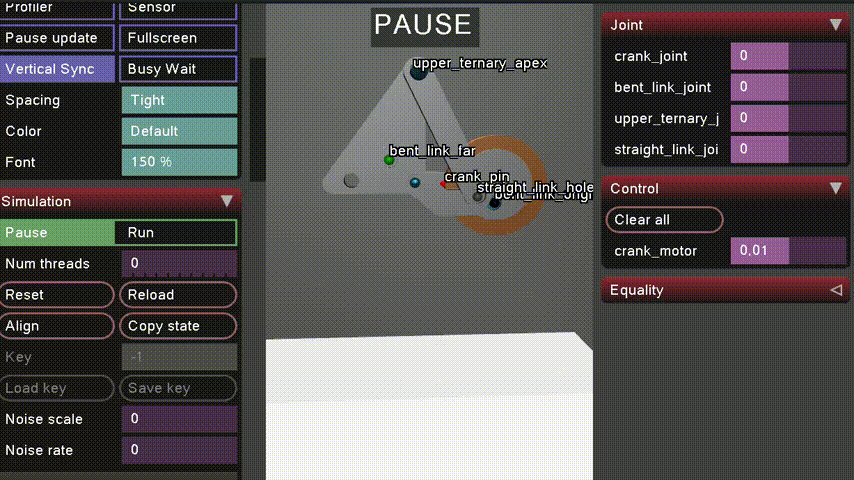
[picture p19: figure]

Figure 15. Equality-constrained sites (labelled) closing the four-bar kinematic loop.


Figure 16. Full single-leg mechanism (“klann_leg”) reconstructed and closed in MuJoCo.

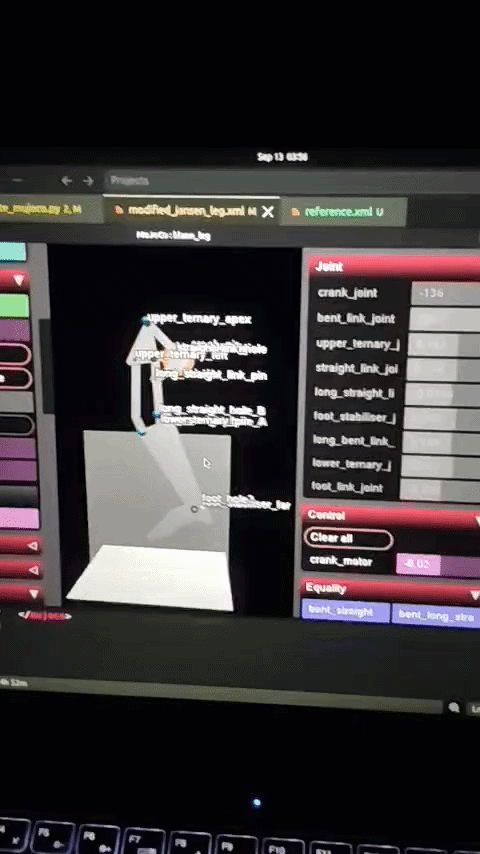
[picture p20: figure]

Figure 17. Iterating on the MJCF description (modified_jansen_leg.xml) alongside the live MuJoCo viewer.

## 5.3 Deformable Shoe and Contact Physics

To estimate realistic foot–ground contact behaviour, a deformable shoe body was added at the foot link, modelled as a soft body rather than a rigid one.

- Attempt 1: with a low number of mesh nodes, the deformable body was unstable and produced unreliable contact behaviour.
- Increasing the node count produced stable results; the overall system was then scaled to match adult foot dimensions.
- With most of the system stable, the deformable shoe began passing through the floor plane under load.

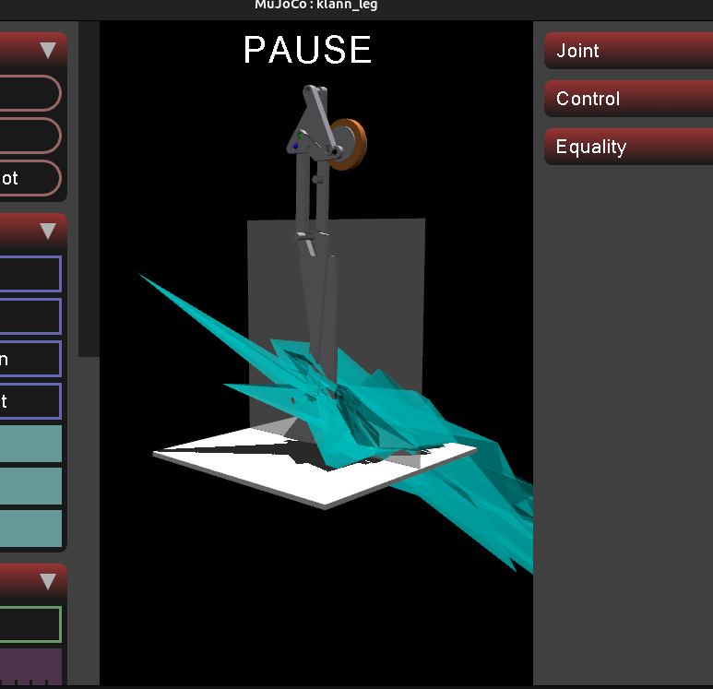
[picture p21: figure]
Deformable shoe passing through floor

Figure 18. Early instability: the deformable shoe penetrating through the floor plane.

This penetration was resolved by tuning the shoe's approximate material properties and the solver's contact-correction behaviour, referring to MuJoCo's contact-physics documentation [9] for the relevant parameters:

young = "8e4" (Young's modulus, lowered for visualisation purposes)

damping = "0.001"

poisson = "0.2"

solref = "0.003 1" (controls how quickly the constraint corrects penetration)

solimp = ".95 .99 .0001"

The width of the floor plane was also increased to prevent contact “bleeding” under a high node count, following a known issue reported against MuJoCo on GitHub.

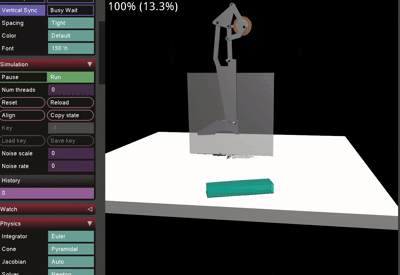
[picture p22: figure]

Figure 19. Deformable shoe resting stably on the floor plane after parameter tuning.

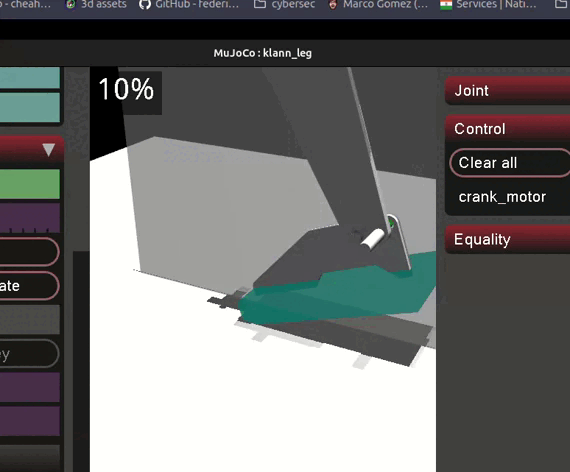
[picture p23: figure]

Figure 20. Shoe visually attached to the foot link of the reconstructed mechanism.

## 5.4 Simulated Contact Loading

With the geometry and contact model in place, the link dimensions and masses were finalised, assuming the links to be aluminium, the shoe to be the mass of a standard adult male shoe (~300 g), and the drive motor's weight to initially be that of a standard 1.7 N motor. Figure 21 shows the theoretical contact force at the FSR location under the base of the big toe, over one walking cycle, at an input torque of 0.08 N·m.

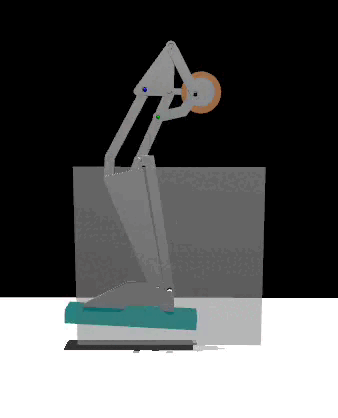
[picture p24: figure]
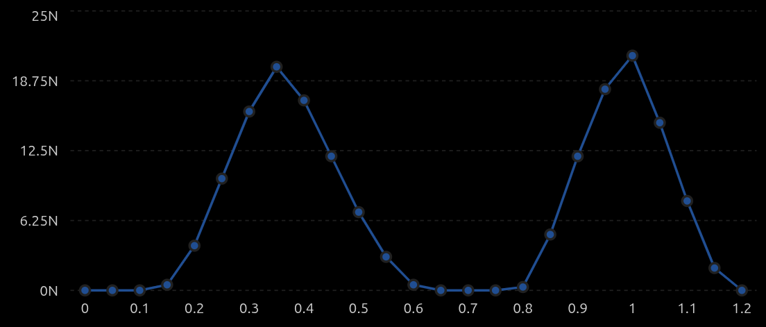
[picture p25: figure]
Theoretical contact force time plot

Figure 21. Theoretical contact force at the big-toe FSR location over one walking cycle, at 0.08 N·m input torque.

# 6. Proposed Hardware

Based on the simulated loading in Section 6.4, the following hardware was proposed for a physical build of the mechanism.

## 6.1 Proposed Components

- 12 V OG555 geared motor with encoder — crank drive.
- ESP32 — main microcontroller.
- BTS7960 (or an equivalent high-power H-bridge capable of handling the 12 V motor).
- AS5600 — for measuring foot orientation at a given time.
- MPU6050 — the standard IMU used for acceleration measurement in this class of project.
- Adafruit Alpha MF01A-N-221-A05 force sensor (rated 1–100 N contact force, <1 ms response, with a mature ESP32-compatible library), used at three standard foot contact points: heel, big toe, and little toe. Alternative: load cell + HX711.
- Mean Well LRS-75-12 power supply — 12 V, 6 A adjustable, providing headroom for future add-ons.

## 6.2 Control Architecture

The proposed control loop drives the crank through a speed/position controller on the ESP32, and closes the loop on foot contact and orientation sensing:

+---------------------------+

| ESP32 MCU |

Desired crank ---->| Speed / Position Controller|

speed | | |

+-------------+---------------+

| PWM / DIR

v

+--------------+

| BTS7960 / |

| H-Bridge |

+------+-------+

+------v-------+

| 12 V OG555 |

| Geared Motor |

+------+-------+

CRANK

+------v-------+

| LINKAGE |

+------+-------+

FOOT

+-------------------+-------------------+

Heel FSR Big-toe FSR Little-toe FSR

+-------------------+-------------------+

v

+--------------+

| ESP32 |

| Contact |

| detection |

+--------------+

Motor encoder ------------------------------> ESP32

AS5600 --------------------------------------> ESP32

MPU6050 -------------------------------------> ESP32

Figure 22. Proposed control architecture: crank speed/position control, closed with foot-contact and orientation sensing.

# 7. Conclusion and Future Work

This project reduced the standard eight-bar Jansen leg to a more compact topology built around a single crank-rocker four-bar, while keeping the mechanism at one degree of freedom and tuning its foot trajectory to sit closer to a human gait than the standard Jansen path. The lower-leg dimensions retained close agreement with the classical Jansen proportions (Section 4), while the upper four-bar was deliberately re-proportioned for the reduced topology and a more compact envelope. Mirroring and coupling the leg into a two-leg, single-input assembly, and animating it in SolidWorks Motion Study, confirmed that the design behaves as intended (Section 5).

The mechanism was then carried substantially further than a CAD exercise: it was reconstructed link-by-link as a physics simulation in MuJoCo, with closed kinematic loops, a deformable contact shoe, and a theoretical contact-force estimate at the big toe (Section 6). That simulated loading, in turn, informed a concrete proposed hardware architecture — drive motor, motor driver, microcontroller, orientation and contact sensing, and power supply — with a defined control loop from desired crank speed through to foot-contact detection (Section 7). Taken together, the project now spans the full path from a first-principles kinematic reduction to a build-ready hardware and control specification.

The most valuable next steps follow directly from where this iteration stopped short:

- Formally verifying the degrees of freedom of the coupled two-leg assembly and the Grashof condition of the driving four-bar using Grübler's equation, rather than relying on the empirical observation in Section 4.2.
- Quantifying the trajectory sweep described in Section 4.2 with a table or plot of pivot separation versus trajectory apex position, instead of the qualitative front-heavy/back-heavy description used here.
- Validating the MuJoCo contact-force estimate (Section 6.4) against the physical prototype once built, and tuning the deformable shoe parameters accordingly.
- Physically fabricating the mechanism and the proposed hardware in Section 7, and closing the control loop on real sensor data rather than simulated values.

# References

[1] Four bar crank-rocker mechanism demonstration. https://www.youtube.com/watch?v=hrvIBtrDNV0

[2] Theo Jansen mechanism walking demonstration. https://www.youtube.com/watch?v=clGEbGLUyoQ

[3] Theo Jansen mechanism build/analysis video. https://www.youtube.com/watch?v=vAEZ4BYAmGE&t=120s

[4] The Jansen leg: a 1-degree-of-freedom planar linkage of eight links, seven revolute joints. ResearchGate figure. https://www.researchgate.net/figure/The-Jansen-leg-a-1-degree-of-freedom-planar-linkage-of-eight-links-seven-revolute_fig2_277606519

[5] Educational model of the Theo Jansen mechanism. https://www.printables.com/model/1503557-educational-model-of-theo-jansen-mechanism

[6] Theo Jansen mechanism reference video. https://www.youtube.com/watch?v=FFuDU1Uiu9k

[7] Reference human walker gait — acceleration carries the local inversion effect in biological motion perception. https://www.researchgate.net/figure/The-full-gait-trajectory-with-the-10-starting-positions-A-and-the-individual-150-ms_fig1_24187266

[8] Closed-loop simulation example (four-bar linkage) in MuJoCo, using equality constraints. https://github.com/google-deepmind/mujoco/issues/172

[9] Reference for deformable-body contact physics parameters used in Section 6.3. https://arxiv.org/html/2411.14701v1

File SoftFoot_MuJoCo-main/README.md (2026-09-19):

# IIT SoftFoot (MJCF)

Requires MuJoCo 3.2.0 or later.

## Overview

This package contains a simplified robot description (MJCF) of the IIT SoftFoot. The original MJCF and assets were provided directly by
[IIT Soft Robotics for Human Cooperation and Rehabilitation group](https://softbots.iit.it/) under an
[BSD-3-Clause License](LICENSE). For more information on the SoftFoot, see the following references:

- [Piazza, C., Della Santina, C., Grioli, G., Bicchi, A. and Catalano, M.G., 2024. Analytical Model and Experimental Testing of the SoftFoot: An Adaptive Robot Foot for Walking Over Obstacles and Irregular Terrains. IEEE Transactions on Robotics.](https://www.doi.org/10.1109/TRO.2024.3415237)
- [Crotti, M., Rossini, L., Pace, A., Grioli, G., Bicchi, A. and Catalano, M.G., 2024. Soft Adaptive Feet for Legged Robots: An Open-Source Model for Locomotion Simulation. IEEE Access, doi: 10.1109/ACCESS.2025.3608584](https://ieeexplore.ieee.org/document/11155105?source=authoralert)

<p float="left">
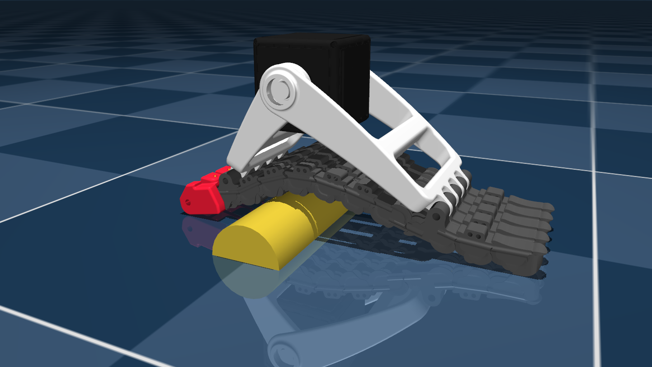
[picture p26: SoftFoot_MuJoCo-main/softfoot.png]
  
</p>

## Usage

The SoftFoot model is intended to be attached as an end effector to a legged robot. This can be achieved through several methods:
- Using the `<attach/>` element in the robot MJCF, and referencing the `attachment_cube` body from the softfoot MJCF. The provided example `scene.xml` uses this method.
- Procedurally attaching it through [`mjSpec`](https://mujoco.readthedocs.io/en/stable/programming/modeledit.html).
- Adding the SoftFoot to the MJCF through the [`mjcf` python module](https://github.com/google-deepmind/dm_control/tree/main/dm_control/mjcf).

## License

This model is released under an [BSD-3-Clause License](LICENSE).

## Publications

If you use this work in an academic context, please cite the following publications:

> Crotti, M., Rossini, L., Hodossy, K. B., Pace, A., Grioli, G., Bicchi, A. and Catalano, M. G.,
> **"Soft Adaptive Feet for Legged Robots: An Open-Source Model for Locomotion Simulation“**,
> in arXiv preprint arXiv:2412.03191, 2024. ([DOI](https://doi.org/10.48550/arXiv.2412.03191))

    @article{anymal2017,
        title={Soft Adaptive Feet for Legged Robots: An Open-Source Model for Locomotion Simulation},
        author={Crotti, Matteo and Rossini, Luca and Hodossy, K. Balint and Pace, Anna and Grioli, Giorgio and Bicchi, Antonio and and Catalano, Manuel G.},
        journal={arXiv},
        volume={},
        number={},
        pages={},
        year={2024},
        publisher={}
        doi = {https://doi.org/10.48550/arXiv.2412.03191}
    }

> Piazza, C., Della Santina, C., Grioli, G., Bicchi, A. and Catalano, M. G.,
> **"Analytical Model and Experimental Testing of the SoftFoot: An Adaptive Robot Foot for Walking Over Obstacles and Irregular Terrains“**,
> in IEEE Transactions on Robotics, 2024. ([DOI](https://www.doi.org/10.1109/TRO.2024.3415237))

    @article{softfoot2024,
        author={Piazza, Cristina and Santina, Cosimo Della and Grioli, Giorgio and Bicchi, Antonio and Catalano, Manuel G.},
        journal={IEEE Transactions on Robotics}, 
        title={Analytical Model and Experimental Testing of the SoftFoot: An Adaptive Robot Foot for Walking Over Obstacles and Irregular Terrains}, 
        year={2024},
        volume={40},
        number={},
        pages={3290-3305},
        keywords={Foot;Robots;Legged locomotion;Stability analysis;Robot kinematics;Shape;Humanoid robots;Adaptive foot;humanoid robots;soft robots},
        doi={10.1109/TRO.2024.3415237}
    }

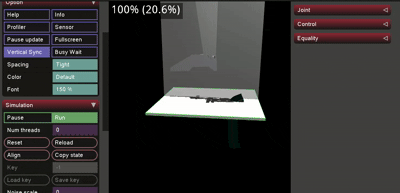
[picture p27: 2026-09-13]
demo/Screencast from 2026-09-13 21-14-38.gif

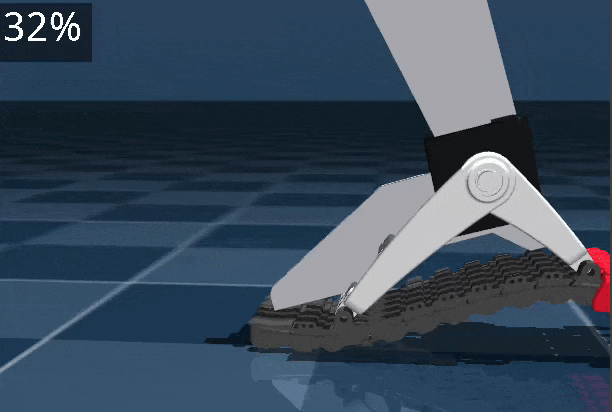
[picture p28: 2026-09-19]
demo/Screencast from 2026-09-18 23-21-16.gif

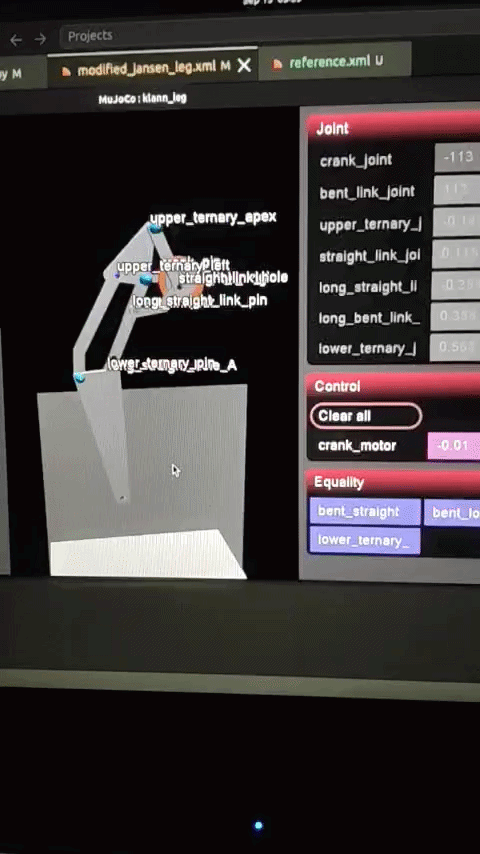
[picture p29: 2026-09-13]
demo/ezgif-3866dedfb55e6fee.gif

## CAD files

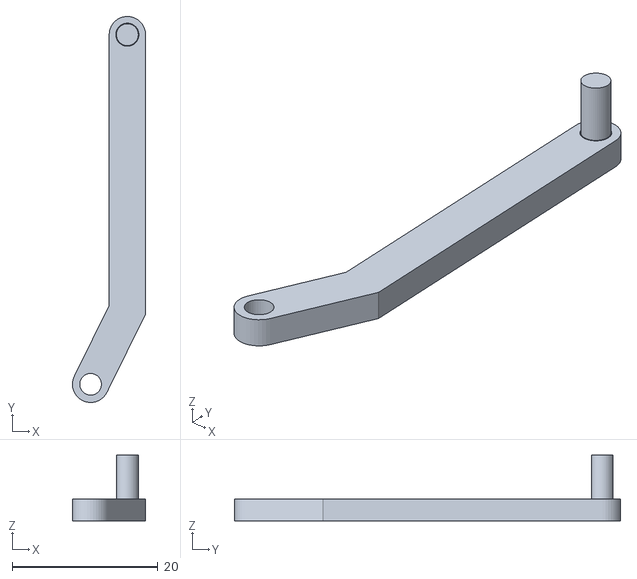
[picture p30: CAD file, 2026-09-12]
meshes/long_bent_link.STL
10.0 x 52.9 x 9.00

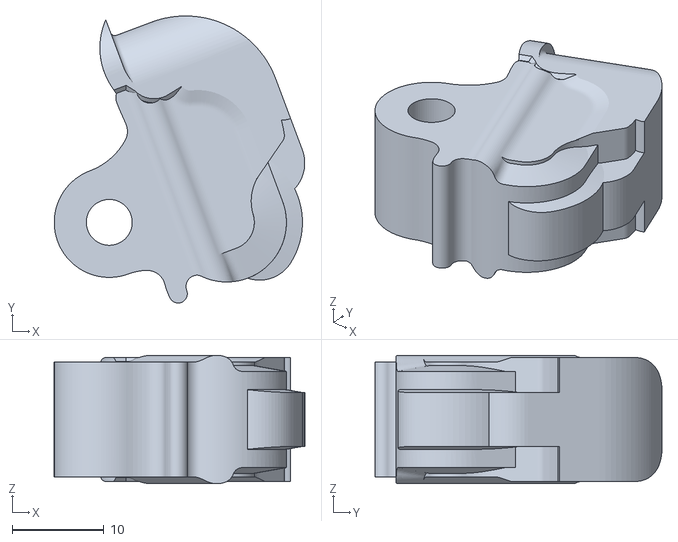
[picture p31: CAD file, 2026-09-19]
SoftFoot_MuJoCo-main/meshes/phalanx_distal_injection.stl
27.3 x 31.3 x 14.0

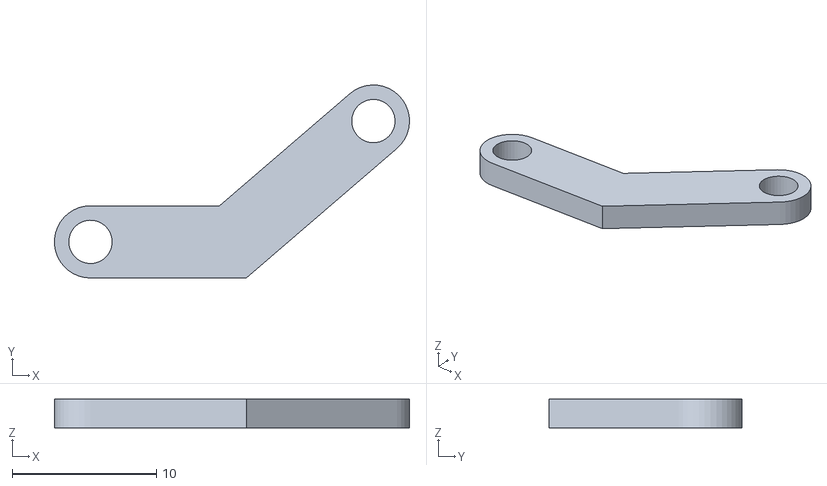
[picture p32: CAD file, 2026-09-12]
meshes/bent_link.STL
24.6 x 13.4 x 2.00

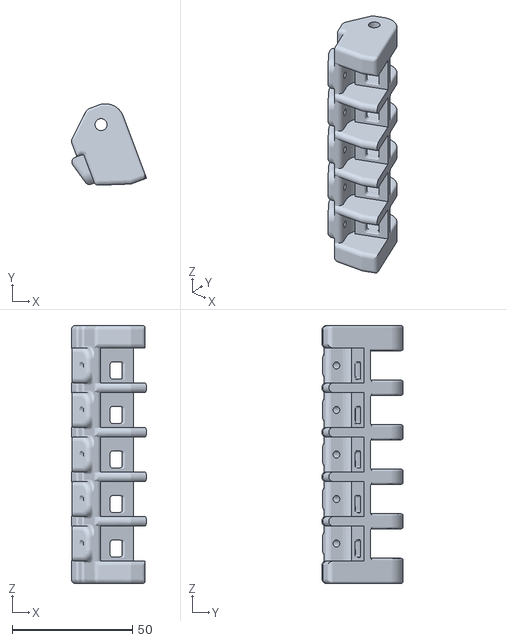
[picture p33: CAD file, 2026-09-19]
SoftFoot_MuJoCo-main/meshes/tacco.stl
31.2 x 33.9 x 107.2

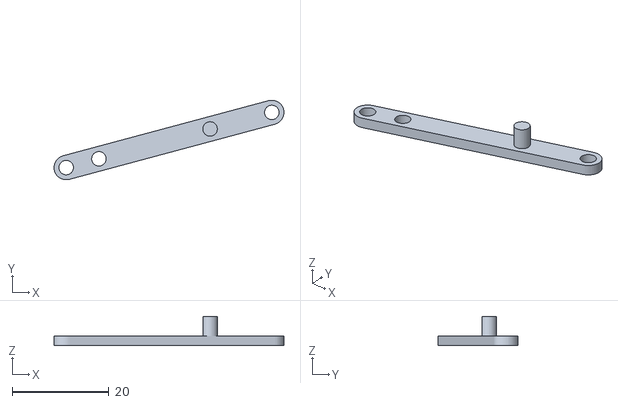
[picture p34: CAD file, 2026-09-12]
meshes/long_straight_link.STL
47.6 x 16.4 x 6.00

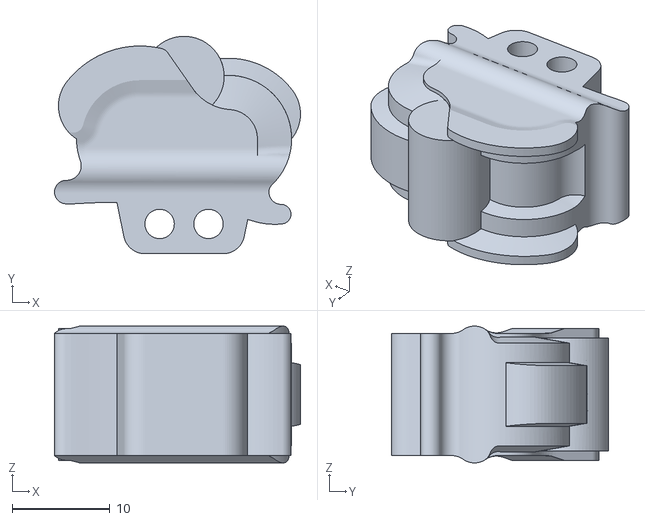
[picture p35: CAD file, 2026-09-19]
SoftFoot_MuJoCo-main/meshes/phalanx_short_injection.stl
25.2 x 22.2 x 14.0

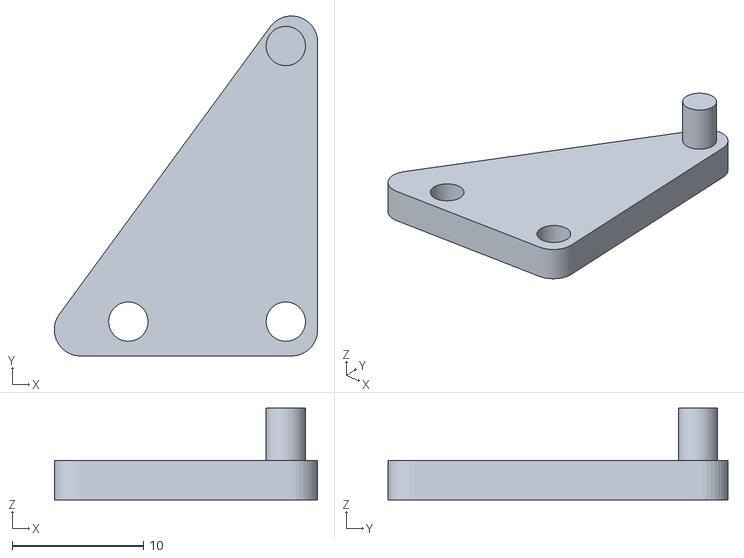
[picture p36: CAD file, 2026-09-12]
meshes/upper_ternary.STL
20.1 x 25.9 x 7.00

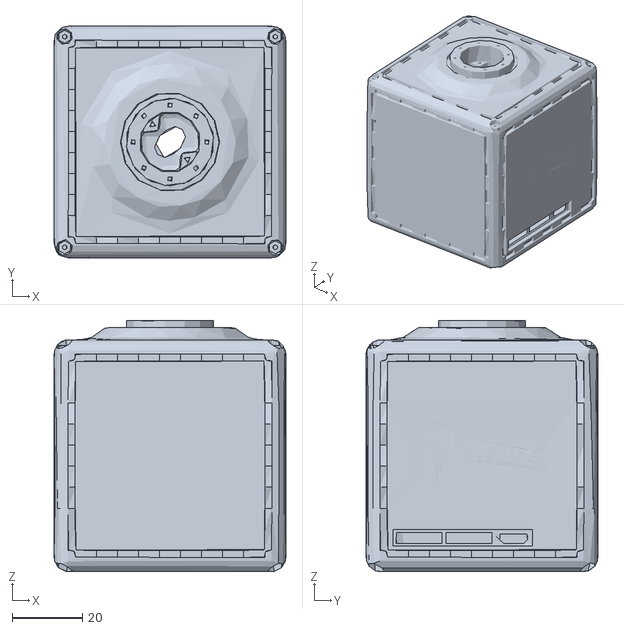
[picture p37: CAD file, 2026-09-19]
SoftFoot_MuJoCo-main/meshes/qb_move_advanced_for_mate.stl
66.0 x 66.0 x 71.5

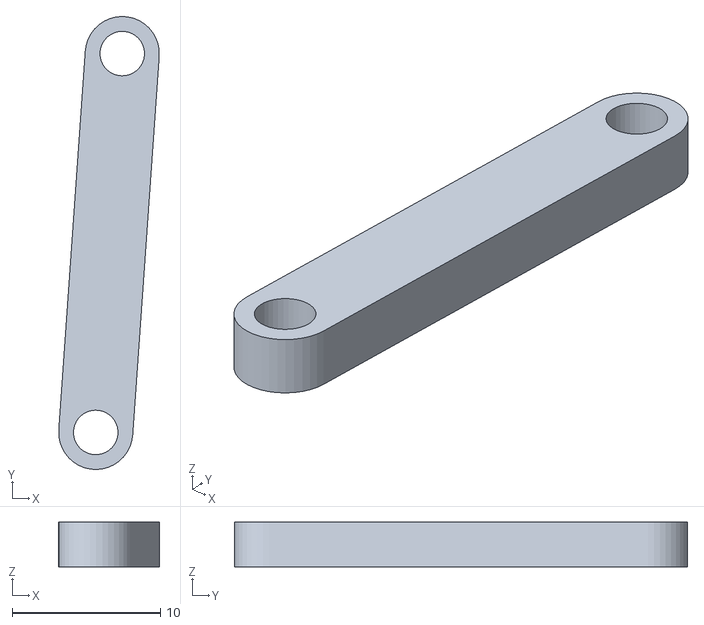
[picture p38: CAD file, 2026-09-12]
meshes/straight_link.STL
6.78 x 30.5 x 3.00

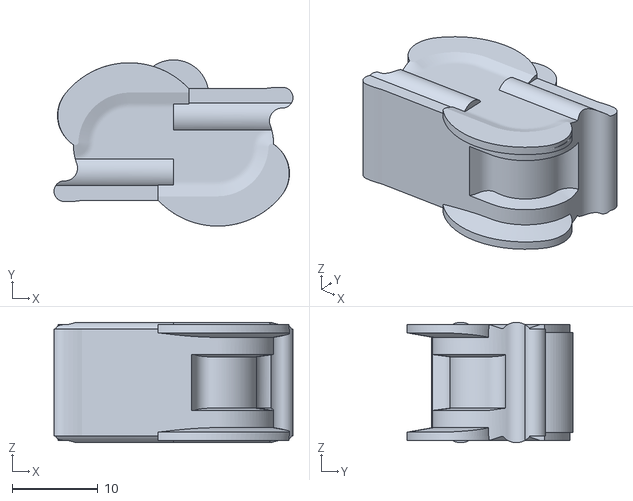
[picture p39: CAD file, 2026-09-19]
SoftFoot_MuJoCo-main/meshes/phlalanx_inv_bijoint.stl
27.8 x 19.3 x 14.0

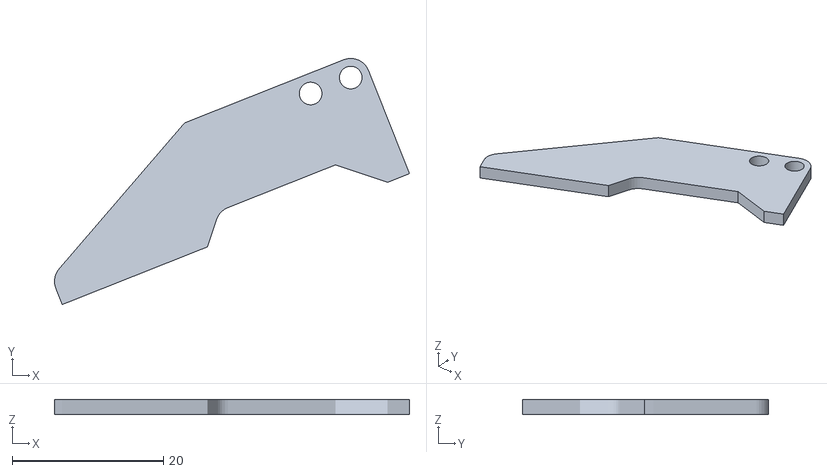
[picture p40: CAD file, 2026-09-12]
meshes/foot_link.STL
47.0 x 32.6 x 2.00

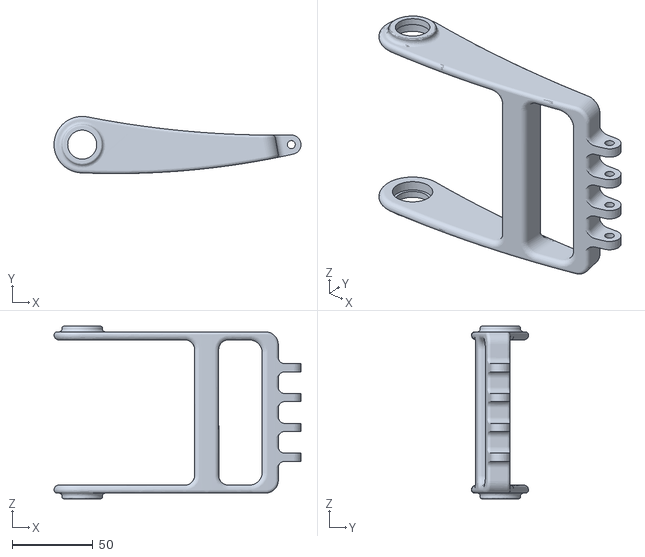
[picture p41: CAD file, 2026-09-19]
SoftFoot_MuJoCo-main/meshes/cube_connection_frontal.stl
153.1 x 35.5 x 107.0

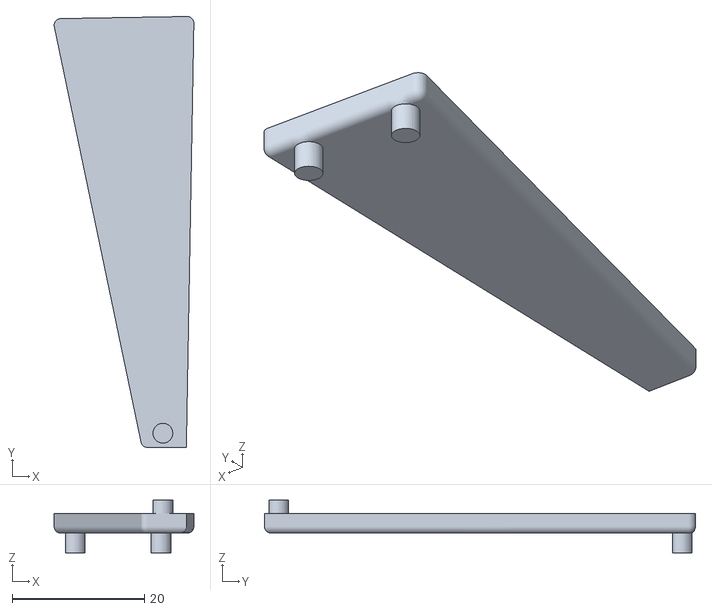
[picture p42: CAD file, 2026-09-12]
meshes/lower_ternary.STL
21.2 x 65.2 x 8.00

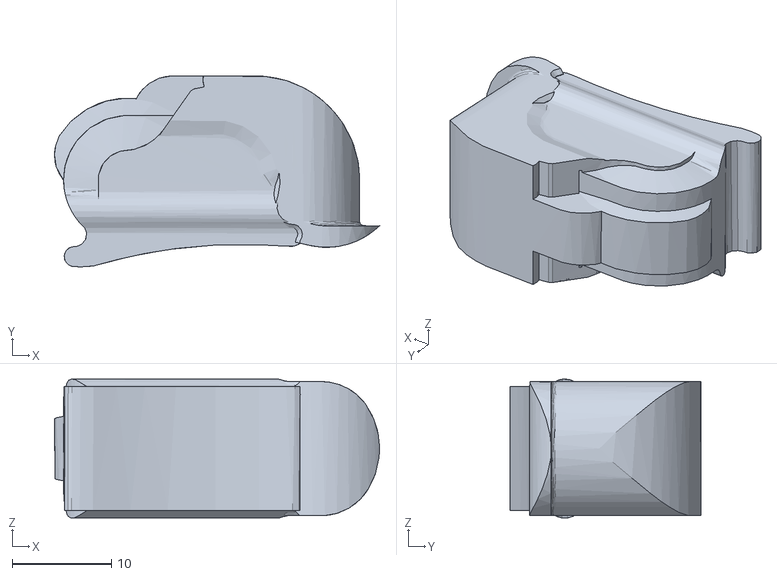
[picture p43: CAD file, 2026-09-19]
SoftFoot_MuJoCo-main/meshes/phalanx_distal_dito.stl
32.7 x 19.2 x 14.0

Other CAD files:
meshes/foot_stabiliser_link.STL
SoftFoot_MuJoCo-main/meshes/phalanx_short_injection2.stl
meshes/ground_link.STL
SoftFoot_MuJoCo-main/meshes/phalanx_inv.stl
SoftFoot_MuJoCo-main/meshes/cube_connection_back.stl

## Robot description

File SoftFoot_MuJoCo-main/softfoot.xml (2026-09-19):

<mujoco model="softfoot">
  
  <compiler meshdir="./meshes/" autolimits="true" angle="radian"/>
  
  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

  <default>
    <default class="standard_chain">
      <joint limited="true" stiffness="0.8" range="-0.15707963267948966 0.78539816339744828" armature="0.001" damping="0.04"/>
      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
    </default>
    
    <default class="collision">
      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
    </default>

    <default class="virtual_pulley">
      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
    </default>
    
    <default class="tendon">
      <tendon limited="true" range="0 0.286" width="0.0004" rgba="0.9 0.7 0.1 1"/>
      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
    </default>
  </default>

  <worldbody>
    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
    <body name="attachment_cube" pos="0 0 0" quat="-0.7071068 0.7071068 0 0">
      <inertial pos="-9.5664949e-05 -1.6749134000000002e-05 0.0013880927000000001" mass="0.45418805000000001" diaginertia="0.000179789 0.00017806823000000001 0.00016882624"/>
      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
      <body name="posterior_arch" pos="0 0 0">
        <inertial pos="-0.030619549999999999 0.042380639999999997 0" mass="0.067640931000000001" fullinertia="9.8002560999999996e-05 8.6292888799999995e-05 4.8226456000000003e-05 2.0310002300000001e-05 -2.77008333e-07 3.4712049800000001e-07"/>
        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
        <body name="heel" pos="-0.052999999999999999 0.072741100000000003 0" quat="0.82192600000000005 0 0 0.56959499999999996">
          <inertial pos="0.0060318100000000003 0.015158100000000001 6.61892e-05" quat="0.98347799999999996 0.000179772 5.11301e-05 0.18102499999999999" mass="0.079565300000000005" diaginertia="8.5032599999999996e-05 7.8342099999999997e-05 1.43078e-05"/>
          <joint name="posterior_arch_to_heel" pos="0 0 0" axis="0 0 1" stiffness="0.001" range="-1.5707963267948966 1.5707963267948966" armature="0.001" damping="0.001"/>
          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
          <body name="phalanx_1_1" pos="0.017380606797550806 -0.012172278537059241 0.036999999999999998" quat="0.82192566568139269 0 0 -0.56959476831709033">
            <joint name="heel_phalanx_1_to_virtual_1_1" class="standard_chain" pos="-0.012999999999999999 0 0" axis="0 0 1.0000000000000002"/>
            <inertial pos="0.0042289199999999997 0.00045861099999999999 -1.66954e-07" quat="0.5 0.5 -0.5 0.5" mass="0.0052390600000000002" diaginertia="2.7888000000000002e-07 2.1992600000000001e-07 1.9004600000000001e-07"/>
            <joint name="virtual_1_1_to_phalanx_1_1" class="standard_chain" pos="0 0 0" axis="0 0 1"/>
            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
            <body name="phalanx_2_1" pos="0.021999999999999999 0 0" quat="1 0 0 0">
              <joint name="phalanx_1_1_to_virtual_2_1" class="standard_chain" pos="-0.012999999999999999 0 0" axis="0 0 1"/>
              <inertial pos="0.0042289199999999997 0.00045861099999999999 -1.66954e-07" quat="0.5 0.5 -0.5 0.5" mass="0.0052390600000000002" diaginertia="2.7888000000000002e-07 2.1992600000000001e-07 1.9004600000000001e-07"/>
              <joint name="virtual_2_1_to_phalanx_2_1" class="standard_chain" pos="0 0 0" axis="0 0 1"/>
              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
              <body name="phalanx_3_1" pos="0.021999999999999999 0 0" quat="1 0 0 0">
                <joint name="phalanx_2_1_to_virtual_3_1" class="standard_chain" pos="-0.012999999999999999 0 0" axis="0 0 1"/>
                <inertial pos="0.0042289199999999997 0.00045861099999999999 -1.66954e-07" quat="0.5 0.5 -0.5 0.5" mass="0.0052390600000000002" diaginertia="2.7888000000000002e-07 2.1992600000000001e-07 1.9004600000000001e-07"/>
                <joint name="virtual_3_1_to_phalanx_3_1" class="standard_chain" pos="0 0 0" axis="0 0 1"/>
                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
                <body name="phalanx_4_1" pos="0.021999999999999999 0 0" quat="1 0 0 0">
                  <joint name="phalanx_3_1_to_virtual_4_1" class="standard_chain" pos="-0.012999999999999999 0 0" axis="0 0 1"/>
                  <inertial pos="0.0042289199999999997 0.00045861099999999999 -1.66954e-07" quat="0.5 0.5 -0.5 0.5" mass="0.0052390600000000002" diaginertia="2.7888000000000002e-07 2.1992600000000001e-07 1.9004600000000001e-07"/>
                  <joint name="virtual_4_1_to_phalanx_4_1" class="standard_chain" pos="0 0 0" axis="0 0 1"/>
                  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
                  <body name="phalanx_5_1" pos="0.021999999999999999 0 0" quat="1 0 0 0">
                    <joint name="phalanx_4_1_to_virtual_5_1" class="standard_chain" pos="-0.012999999999999999 0 0" axis="0 0 1"/>
                    <inertial pos="0.0042289199999999997 0.00045861099999999999 -1.66954e-07" quat="0.5 0.5 -0.5 0.5" mass="0.0052390600000000002" diaginertia="2.7888000000000002e-07 2.1992600000000001e-07 1.9004600000000001e-07"/>
                    <joint name="virtual_5_1_to_phalanx_5_1" class="standard_chain" pos="0 0 0" axis="0 0 1"/>
                    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
                    <body name="reverse_phalanx_1" pos="0.021999999999999999 0 0" quat="1 0 0 0">
                      <joint name="phalanx_5_1_to_virtual_6_1" class="standard_chain" pos="-0.012999999999999999 0 0" axis="0 0 1"/>
                      <inertial pos="0.00514694 0.0015980499999999999 -1.0975099999999999e-05" quat="0 0.70710700000000004 0 0.70710700000000004" mass="0.0048234200000000001" diaginertia="2.3400300000000001e-07 2.2119899999999999e-07 1.46524e-07"/>
                      <joint name="virtual_6_1_to_reverse_phalanx_1" class="standard_chain" pos="0 0 0" axis="0 0 1"/>
                      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
                      <body name="rollover_phalanx_1" pos="0.023300000000000001 0 0" quat="1 0 0 0">
                        <joint name="reverse_phalanx_1_to_virtual_7_1" class="standard_chain" pos="-0.012999999999999999 0 0" axis="0 0 1" range="-0.78539816339744828 0.15707963267948966"/>
                        <inertial pos="0.0098241600000000002 -0.00192716 1.2476099999999999e-07" mass="0.0069295499999999996" diaginertia="3.2379098000000002e-07 4.8681188999999998e-07 6.2561966999999998e-07"/>
                        <joint name="virtual_7_1_to_rollover_phalanx_1" class="standard_chain" pos="0 0 0" axis="0 0 1" range="-0.78539816339744828 0.15707963267948966"/>
                        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
                        <body name="phalanx_6_1" pos="0.032000000000000001 0 0" quat="1 0 0 0">
                          <joint name="rollover_phalanx_1_to_virtual_8_1" class="standard_chain" pos="-0.012999999999999999 0 0" axis="0 0 1"/>
                          <inertial pos="0.0047710799999999996 0.00045861099999999999 1.66954e-07" quat="0.5 0.5 -0.5 0.5" mass="0.0052390600000000002" diaginertia="2.7888000000000002e-07 2.1992600000000001e-07 1.9004600000000001e-07"/>
                          <joint name="virtual_8_1_to_phalanx_6_1" class="standard_chain" pos="0 0 0" axis="0 0 1"/>
                          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
                          <body name="distal_phalanx_1" pos="0.021999999999999999 0 0" quat="1 0 0 0">
                            <joint name="phalanx_6_1_to_virtual_9_1" class="standard_chain" pos="-0.012999999999999999 0 0" axis="0 0 1"/>
                            <inertial pos="0.0109173 0.0020369099999999998 1.0586999999999999e-07" quat="0.020442700000000001 0.70681099999999997 -0.020442700000000001 0.70681099999999997" mass="0.0095589200000000003" diaginertia="7.4876999999999995e-07 6.58265e-07 3.0432000000000001e-07"/>
                            <joint name="virtual_9_1_to_distal_phalanx_1" class="standard_chain" pos="0 0 0" axis="0 0 1"/>
                            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
                          </body>
                        </body>
                      </body>  
                    </body>  
                  </body>                 
                </body>             
              </body>             
            </body>            
          </body>
          
          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
          <body name="phalanx_1_2" pos="0.017380606797550806 -0.012172278537059241 0.018499999999999999" quat="0.82192566568139269 0 0 -0.56959476831709033">
            <joint name="heel_phalanx_2_to_virtual_1_2" class="standard_chain" pos="-0.012999999999999999 0 0" axis="0 0 1.0000000000000002"/>
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

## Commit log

2026-09-12 added meshes for all individual links+ draft MJCF
    [bent_link.STL, foot_link.STL, foot_stabiliser_link.STL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]
2026-09-19 milestone: version 1 stable
    [cube_connection_back.stl, cube_connection_frontal.stl, phalanx_distal_dito.stl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]
